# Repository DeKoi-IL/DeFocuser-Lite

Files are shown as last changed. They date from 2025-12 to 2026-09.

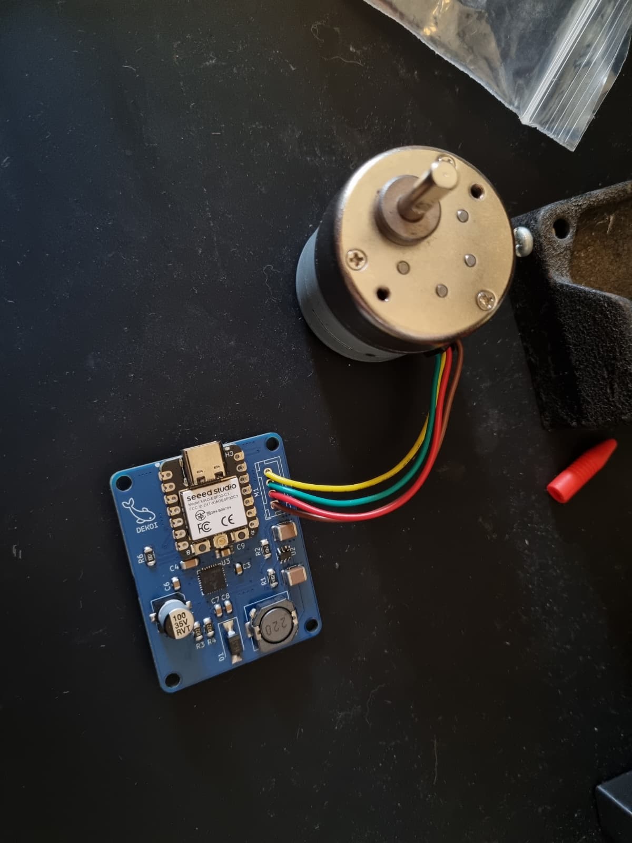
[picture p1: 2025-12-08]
Images/Assembly.jpg

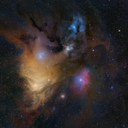
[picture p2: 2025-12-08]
Code/ASCOM_Driver/Resources/dekoi.bmp

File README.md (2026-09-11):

# DeFocuser-Lite
An open source DIY focus motor with automatic range calibration.

This focuser uses the same motor used by ZWO in the older EAF models (Non pro models)
The 3d models are also modelled based on ZWO's front plate so whatever focuser the eaf is compatible with, this is also compatible.
Powered by USB C 5V.
Includes a single button for manual focusing (each press changes direction).




## 3D Models

There are multiple versions for models.
You can get the motor ZWO used in their older models (described below, imaged above)
Or you could use a basic BYJ motor with a simple modification (How to modify: https://www.youtube.com/watch?v=kCoWSqSAGug)
Its great for lenses with suitable reduction!
WhatsApp Image 2026-03-04 at 00 19 02
WhatsApp Image 2026-01-04 at 11 39 28
WhatsApp Image 2026-03-04 at 00 26 04

Or you could retrofit the motor and front plate of the really old 12V ZWO focuser
WhatsApp Image 2026-01-10 at 22 27 24

All versions can be found in the 3d models folder

## App
Each app instance owns one focuser (one COM port) and funnels commands from multiple ASCOM clients to that focus motor. Run one instance per focuser — e.g. a main scope and a piggybacked guide/lens defocuser.

The hub owns all configuration, including which focuser ASCOM clients talk to: the driver has no setup dialog of its own, and pressing Setup in NINA/SGP just brings the hub forward. With a single focuser there is nothing to configure — the first hub to connect claims the ASCOM slot. Running several, click **Use this hub** in the Connection panel of the one you want ASCOM to drive.
The app has many extra controls not possible to implement in control software like nina, sgp etc...


## Disclaimer
This is NOT a beginner friendly project, since its all SMD components.
But this also is not a hard SMD project, just need the right tools.
Mainly a hot plat and\or hot air gun.
This is one of my first SMD projects, and im positive this has a LOT of room for improvement.
Please do feel free to reach out for contribution!

## BOM
For the motor you need to search for this motor: 35YF22GN120R-TF0
I bought it from this Ali Express seller (cheapest i found), but feel free to try and source it yourself:
https://he.aliexpress.com/item/1005004214871047.html

Technically, this should work with any 2 phase 4 wire stepper motor (as long as it doesn't draw too much current).
You'd just need to redesign the 3d model to fit your motor.

I've actually tested on a Nema17 39mm motor, and it seems to work fine, albeit low torque obviously.

The rest of the components are in the kicad folder BOM file.
*note: In the kicad project some components have LCSC part numbers, and some dont.
This is due to me using components i already had, and the rest i ordered from LCSC.
For the components without LCSC part number, you can just search by name in ali express for example.

## Hardware
The connection holes are meant to be fit with m3\4 heatset inserts (these: https://he.aliexpress.com/item/1005007481465353.html)
The PCB and backplate are held with m2 heatset inserts with m2 6mm screws.

## Software
The software is originally based on DarkSkyGeek's OAG focuser project.
A lot of the code has changed, most of it is different.
I'd like to  thank Julian for the inspiration 🙏

The current shipped app is a WPF rewrite (`Code/FocuserApp`) that replaces the older WinForms mediator (kept around as `Code/Focuser_App-Legacy/` for reference). It owns the serial connection to the focuser, exposes it to ASCOM clients via named pipes, and gives you a manual control UI on top.

This will allow multiple client connections to the focuser and give extra functionalities like:
- Auto\Manual limits calibration
- Manually settings position, max steps, reverse direction and more..
- Per-motor stall-detection sensitivity slider
- Speed selection (Fast / Normal / Slow)
- Live serial console (TX/RX, app events)

### Installing the app
The pre-built installer lives in the `Installer/` folder at the repo root:

```
Installer/DeKoi DeFocuser Lite Setup-<version>.exe
```

Run it. It installs both the ASCOM driver DLL (`ASCOM.DeKoi.DeFocuserLite.dll`) and the controller app (`ASCOM.DeKoi.DeFocuserApp.exe`), and registers the driver for COM under both 32-bit and 64-bit `regasm`. Requires ASCOM Platform 6.2 or later — the installer checks and bails out with a message if you don't have it.

If you want the prior WinForms version, the legacy installer source sits in `Code/Installer-Legacy/` and the legacy WinForms app in `Code/Focuser_App-Legacy/`. The standalone driver/installer that pre-dates all of this is preserved in `Code/Software-Legacy/`.

### Flashing the firmware
To flash the firmware on the ESP32, simply go to the arduino firmware folder, open the ino file in arduino IDE, compile and upload.
Make sure to have the ESP32 boards setup (Board manager) and set Xiao ESP32C3 (or S3)
And the following libraries:
- TMCStepper library by teemuatlut.
- EspSoftSerial by Dirk Kaar, Peter Lerup

## Building from source
The repo ships a one-shot build pipeline (`build.cmd` / `build.ps1`) that patches assembly versions, builds the ASCOM driver + the WPF controller, and compiles the Inno Setup installer in one go.

### Prerequisites
- Visual Studio 2019 / 2022 (Community / Pro / Enterprise / BuildTools — anything with MSBuild). The script auto-locates `MSBuild.exe`.
- [Inno Setup 6](https://jrsoftware.org/isdl.php) — script auto-locates `ISCC.exe`.
- ASCOM Platform 6.2 or later (the driver references `ASCOM.Utilities`).
- For the firmware: Arduino IDE with ESP32 boards + the libraries listed above.

### Build commands
From a regular `cmd.exe` prompt:

```cmd
build.cmd 2.1.0
build.cmd 2.1.0 -OutputDir D:\Releases
build.cmd 2.1.0 -SkipBuild
build.cmd 2.1.0 -Configuration Debug
```

From PowerShell:

```powershell
.\build.ps1 -Version 2.1.0
.\build.ps1 -Version 2.1.0 -OutputDir D:\Releases
.\build.ps1 -Version 2.1.0 -SkipBuild
.\build.ps1 -Version 2.1.0 -Configuration Debug
```

What it does:
1. Patches `AssemblyVersion` + `AssemblyFileVersion` in `Code/FocuserApp/Properties/AssemblyInfo.cs` and `Code/ASCOM_Driver/Properties/AssemblyInfo.cs`.
2. Builds the ASCOM driver (`Release | AnyCPU`).
3. Builds the WPF app (`Release | x64`).
4. Compiles `Code/FocuserApp/Installer/Setup.iss` with `ISCC`, injecting `/DMyAppVersion=<version>`.
5. Drops the resulting `DeKoi DeFocuser Lite Setup-<version>.exe` into `Installer/` (or whatever you pass to `-OutputDir`).

The fonts used by the app are **Inter** (UI) and **JetBrains Mono** (numeric readouts). Both are free OFL fonts; install them system-wide for pixel-perfect rendering — fallback to system fonts otherwise.

## Automatic limits calibration
This is very motor and configuration specific.
Not every motor behaves the same since the TMC's way of detecting stalls is back EMF measurement, and your motor might not behave as well as mine with the same configurations.

The first place to tune is the **Stall sense** slider in the controller app's Focuser Settings card — it scrubs the TMC's `SGTHRS` register from `128` (most sensitive) to `255` (least sensitive). The value persists to EEPROM, so you only set it once. Default is `211`.

If the slider alone doesn't get you where you want, there are a few firmware-side parameters you can tweak in `Code/Arduino_Firmware/Arduino_Firmware.ino`:

```
#define STALL_COUNT_THRESHOLD 2 // How many time should the stall interrupt be raised before we consider real stall
#define STALL_TIME_THRS 300     // In what time frame should these stalls be detected (in milliseconds)
#define STALL_GRACE_PERIOD 1000 // When starting motor, there are many false detections, how long should we ignore stall detections (in milliseconds)
```

Lets say the motor hits a hard physical limit but motor still makes noise trying to move (IE stall wasn't detected),
Try changing one of the following one by one (changing multiple parameters might make fine tuning harder):
- **Stall sense slider** = Start by sliding it toward the "Most sensitive" end, see if the stall is detected sooner.
- `STALL_TIME_THRS` = Increase this to allow slow stall detections to accumulate.
- `STALL_COUNT_THRESHOLD` = You could reduce this, but i suggest not doing that since that might increase false detections.

If this doesn't work, set `DEBUG` to `1` and watch the stall logs in the app's console — you'll see how often (or whether) stalls get detected. If they don't fire at all, or fire too slowly, slide stall sense further toward "Most sensitive".

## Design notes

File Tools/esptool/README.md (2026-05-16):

# esptool.exe (required for firmware updates)

The hub bundles `esptool.exe` so it can flash ESP32-C3 firmware updates over
the existing USB-serial connection — no Python install needed on user
machines.

## Drop the binary here

Place the Windows single-file build of esptool at:

```
Tools/esptool/esptool.exe
```

Download the latest standalone Windows release from:
<https://github.com/espressif/esptool/releases>

Pick the asset named like `esptool-vX.Y.Z-win64.zip`, extract, and copy
`esptool.exe` into this folder. Tested with v4.7+ (any version that supports
the `esp32c3` chip target works).

## What uses it

- **Build** — `build.ps1` does not require esptool itself, but the installer
  (`Code/FocuserApp/Installer/Setup.iss`) picks the binary up from this folder
  via `Source: "Tools\esptool\esptool.exe"`. The line is marked
  `skipifsourcedoesntexist`, so a missing binary will silently skip bundling
  rather than break the build, but the hub's firmware-update feature will be
  disabled on user installs.
- **Runtime** — `Services/FirmwareFlasher.cs` resolves the bundled binary at
  `{app}\tools\esptool.exe` and invokes it with:
  ```
  esptool.exe --chip esp32c3 --port COMx --baud 921600 \
      --before default_reset --after hard_reset \
      write_flash 0x0 firmware.bin
  ```

## Why not auto-download?

Keeping the binary out of git avoids a ~10MB blob in version history. CI or
release pipelines can fetch it via the URL above during the release build.

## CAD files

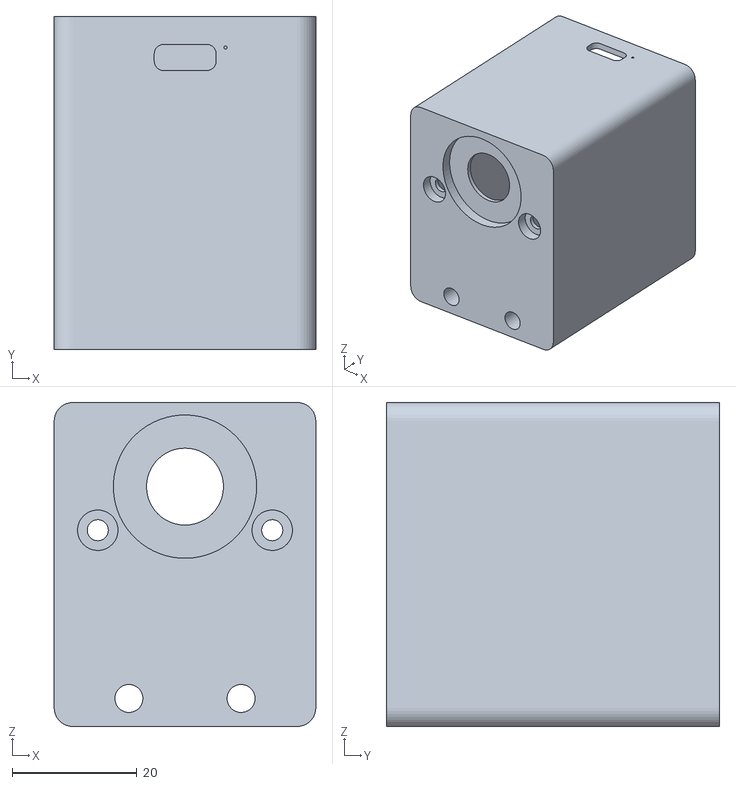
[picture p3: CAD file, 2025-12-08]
3D Models/Body.stl
42.0 x 53.5 x 52.0

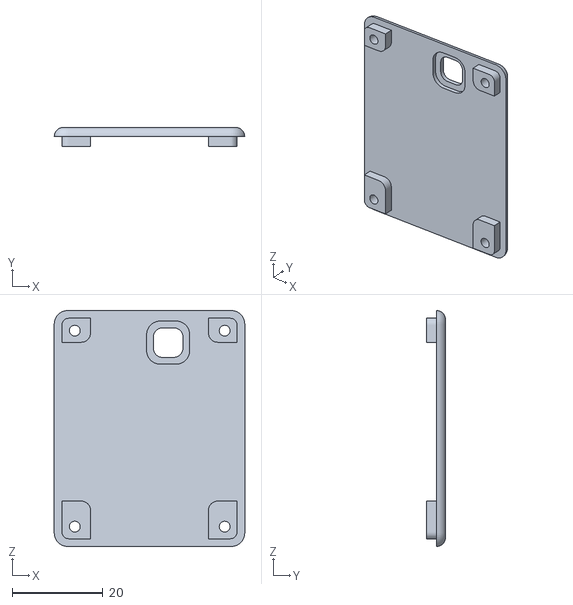
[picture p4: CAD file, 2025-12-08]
3D Models/BackPlate.stl
42.0 x 4.20 x 52.0

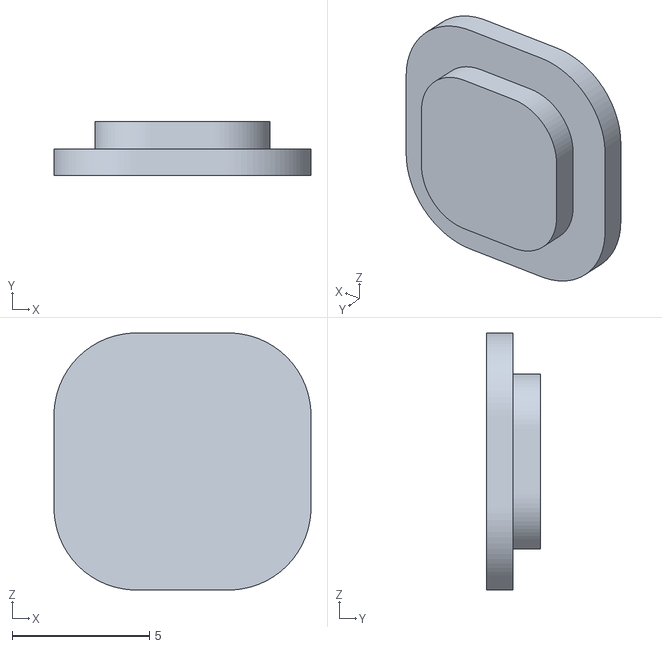
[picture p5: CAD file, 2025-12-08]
3D Models/Button.stl
9.35 x 1.95 x 9.35

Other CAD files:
3D Models/DeFocuser Lite.f3d

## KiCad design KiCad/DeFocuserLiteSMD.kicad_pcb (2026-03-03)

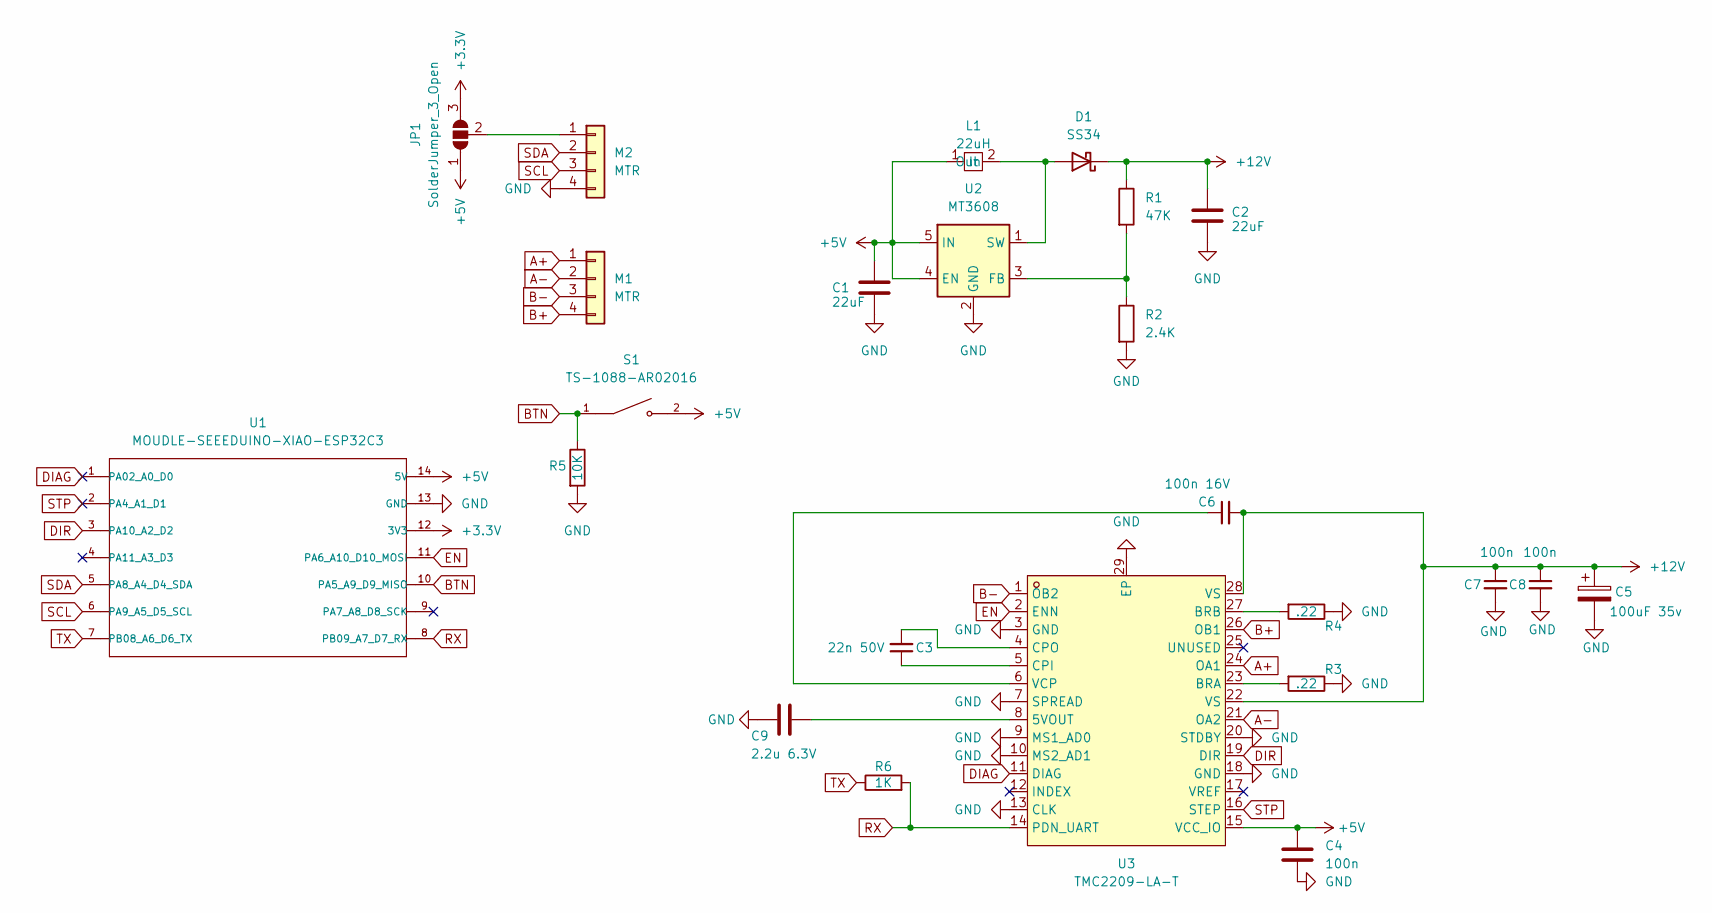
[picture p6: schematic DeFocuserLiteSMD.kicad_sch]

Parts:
C1, C2: 22uF; C_1812_4532Metric; LCSC Part C5348165
C3: 22n 50V; C_0805_2012Metric; LCSC Part C2175869
C4: 100n; C_1206_3216Metric; LCSC Part C2180991
C5: 100uF 35v; CP_Elec_6.3x7.7; LCSC Part C2836442
C6: 100n 16V; R_0805_2012Metric; LCSC Part C2170367
C7, C8: 100n; C_0805_2012Metric; LCSC Part C2170367
C9: 2.2u 6.3V; C_0805_2012Metric; LCSC Part C520034
D1: SS34; D_SMA-SMB_Universal_Handsoldering; LCSC Part C908680
JP1: SolderJumper_3_Open; SolderJumper-3_P1.3mm_Open_RoundedPad1.0x1.5mm_NumberLabels
L1: 22uH; Inductor_CDRH104R; LCSC Part C87002
M1, M2: MTR; JST_XH_B4B-XH-A_1x04_P2.50mm_Vertical
R1: 47K; R_1206_3216Metric_Pad1.30x1.75mm_HandSolder; LCSC Part C2933708
R2: 2.4K; R_1206_3216Metric_Pad1.30x1.75mm_HandSolder; LCSC Part C2907446
R3, R4: .22; R_1210_3225Metric; LCSC Part C137099
R5: 10K; R_1206_3216Metric; LCSC Part C17902
R6: 1K; R_1206_3216Metric; LCSC Part C2907440
S1: TS-1088-AR02016; SW_TS-1088-AR02016; PARTREV N/A; LCSC Part C720477
U1: MOUDLE-SEEEDUINO-XIAO-ESP32C3; XIAO-ESP32C3-SMD
U2: MT3608; SOT-23-6; LCSC Part C84817
U3: TMC2209-LA-T; QFN-28_L5.0-W5.0-P0.50-BL-EP; LCSC Part C2150710

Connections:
+3.3V: JP1.3 (B), U1.12 (3V3)
+5V: C1.1, C4.1, JP1.1 (A), L1.1 (In), S1.2, U1.14 (5V), U2.4 (EN), U2.5 (IN), U3.15 (VCC_IO)
+12V: C2.1, C5.1, C6.2, C7.1, C8.1, D1.1 (K), R1.1, U3.22 (VS), U3.28 (VS)
A+: M1.1, U3.24 (OA1); also elsewhere on the board
A-: M1.2, U3.21 (OA2); also elsewhere on the board
B+: M1.4, U3.26 (OB1); also elsewhere on the board
B-: M1.3, U3.1 (OB2); also elsewhere on the board
BTN: R5.1, S1.1, U1.10 (PA5_A9_D9_MISO)
DIAG: U1.1 (PA02_A0_D0), U3.11 (DIAG)
DIR: U1.3 (PA10_A2_D2), U3.19 (DIR)
EN: U1.11 (PA6_A10_D10_MOSI), U3.2 (ENN)
GND: C1.2, C2.2, C4.2, C5.2, C7.2, C8.2, C9.2, M2.4, R2.2, R3.1, R4.1, R5.2, U1.13 (GND), U2.2 (GND), U3.3 (GND), U3.7 (SPREAD), U3.9 (MS1_AD0), U3.10 (MS2_AD1), U3.13 (CLK), U3.18 (GND), U3.20 (STDBY), U3.29 (EP); also elsewhere on the board
unnamed: D1.2 (A), L1.2 (Out), U2.1 (SW)
unnamed 13: JP1.2 (C), M2.1; also elsewhere on the board
unnamed: R1.2, R2.1, U2.3 (FB)
unnamed: C9.1, U3.8 (5VOUT)
unnamed: R3.2, U3.23 (BRA)
unnamed: R4.2, U3.27 (BRB)
unnamed: C3.1, U3.5 (CPI)
unnamed: C3.2, U3.4 (CPO)
unnamed: C6.1, U3.6 (VCP)
RX: R6.2, U1.8 (PB09_A7_D7_RX), U3.14 (PDN_UART)
SCL: M2.3, U1.6 (PA9_A5_D5_SCL); also elsewhere on the board
SDA: M2.2, U1.5 (PA8_A4_D4_SDA); also elsewhere on the board
STP: U1.2 (PA4_A1_D1), U3.16 (STEP)
TX: R6.1, U1.7 (PB08_A6_D6_TX)

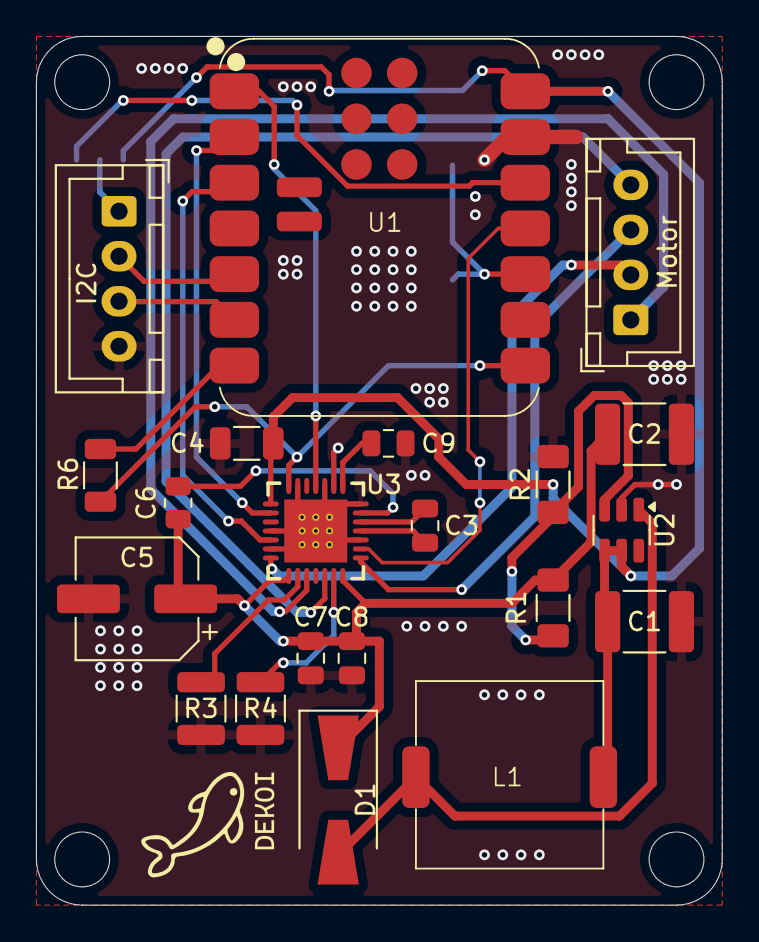
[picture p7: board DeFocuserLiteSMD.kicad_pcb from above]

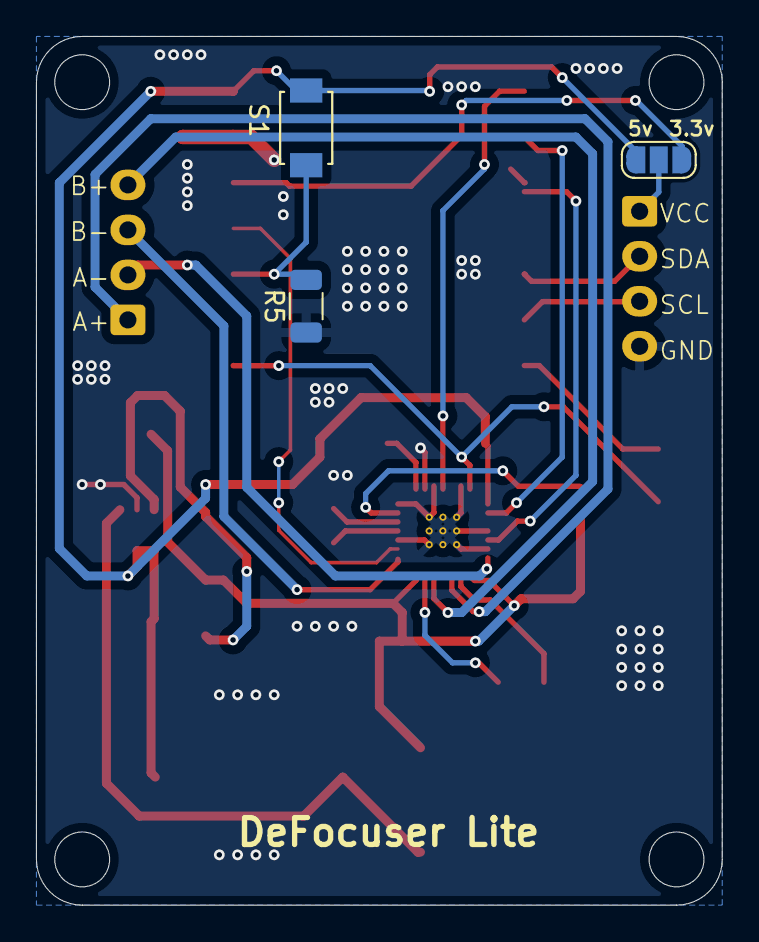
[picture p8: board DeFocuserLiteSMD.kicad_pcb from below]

Board: 2 copper layers, 38.1 x 48.3 mm, 24 parts (3 on the bottom side), 26 nets.

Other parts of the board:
I2C: MTR; JST_XH_B4B-XH-A_1x04_P2.50mm_Vertical
Motor: MTR; JST_XH_B4B-XH-A_1x04_P2.50mm_Vertical

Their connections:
A+: Motor.1; also elsewhere on the board
A-: Motor.2; also elsewhere on the board
B+: Motor.4; also elsewhere on the board
B-: Motor.3; also elsewhere on the board
GND: I2C.4; also elsewhere on the board
unnamed 13: I2C.1; also elsewhere on the board
SCL: I2C.3; also elsewhere on the board
SDA: I2C.2; also elsewhere on the board

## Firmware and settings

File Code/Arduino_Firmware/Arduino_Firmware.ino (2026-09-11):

#include <TMCStepper.h>
#include <SoftwareSerial.h>
#include <EEPROM.h>

#define DEBUG 0

// Board select. Bare tokens need distinct values, otherwise the #if/#elif
// comparisons below all collapse to 0 == 0 (undefined identifier -> 0) and
// the first branch always wins regardless of what MCU is set to.
#define ESP32C3     1  // current SMD board: I2C pins (D4/GPIO6, D5/GPIO7) freed to header M2
#define ESP32C3_OLD 2  // pre-rev board: STEP/DIR sat on the I2C pins
#define ESP32S3     3

// Default for a bare `arduino-cli compile`. build.ps1 passes -DMCU=... per
// variant, so a release build never rewrites this file. The pre-rev board is
// the default because every unit predating the SMD revision uses it.
#ifndef MCU
  #define MCU ESP32C3_OLD
#endif

// BOARD_ID is what the firmware reports over COMMAND:FOCUSER:GETBOARD and what
// the release .bin is named after. Keep the three in sync: a mismatch is how
// 2.3.0 shipped new-board pins to pre-rev hardware.
#if MCU == ESP32C3
  #define EN_PIN    10  // Enable          (D10 / GPIO10)
  #define DIR_PIN   4   // Direction       (D2  / GPIO4)
  #define STEP_PIN  3   // Step            (D1  / GPIO3)
  #define DIAG_PIN  2   // Stall detection (D0  / GPIO2)
  #define SW_RX 20
  #define SW_TX 21
  #define BUTTON_PIN 9
  #define BOARD_ID "esp32c3"
#elif MCU == ESP32C3_OLD
  #define EN_PIN    10  // Enable
  #define DIR_PIN   7   // Direction       (D5 / GPIO7 / SCL)
  #define STEP_PIN  6   // Step            (D4 / GPIO6 / SDA)
  #define DIAG_PIN  4   // Stall detection (D2 / GPIO4)
  #define SW_RX 20
  #define SW_TX 21
  #define BUTTON_PIN 9
  #define BOARD_ID "esp32c3-old"
#elif MCU == ESP32S3
  #define EN_PIN    9   // Enable          (D10 / GPIO9)
  #define DIR_PIN   3   // Direction       (D2  / GPIO3)
  #define STEP_PIN  2   // Step            (D1  / GPIO2)
  #define DIAG_PIN  1   // Stall detection (D0  / GPIO1)
  #define SW_RX 44
  #define SW_TX 43
  #define BUTTON_PIN 8
  #define BOARD_ID "esp32s3"
#endif

#define DRIVER_SERIAL_BAUD 57600

#define MAX_SPEED_DELAY 8000
#define MIN_SPEED_DELAY 14000

#define ACCELERATION_TIME 1000.0

#define DRIVER_ADDRESS 0b00  // TMC2209 address pin configuration
#define R_SENSE 0.22f        // Sense resistor value

//-- Constants ----------------------------------------------------------------

constexpr auto DEVICE_GUID = "dfafe960-d19c-4abd-af4a-4dc5f49775a3";

constexpr auto MSG_OK = "OK";
constexpr auto MSG_NOK = "NOK";

constexpr auto TRUE = "TRUE";
constexpr auto FALSE = "FALSE";

constexpr auto COMMAND_PING = "COMMAND:PING";
constexpr auto RESULT_PING = "RESULT:PING:OK:";

constexpr auto COMMAND_INFO = "COMMAND:INFO";
// build.ps1 patches the v__FIRMWARE_VERSION__ token in place before compile.
constexpr auto RESULT_INFO = "RESULT:INFO:DeKoi's DeFocuser Lite Firmware v2.4.1";

// Lets the hub confirm which pinout is actually running before it offers a
// firmware update, so a wrong pick in the MCU dropdown can be caught.
constexpr auto COMMAND_FOCUSER_GETBOARD = "COMMAND:FOCUSER:GETBOARD";
constexpr auto RESULT_FOCUSER_BOARD = "RESULT:FOCUSER:BOARD:";

constexpr auto COMMAND_FOCUSER_GETPOSITION = "COMMAND:FOCUSER:GETPOSITION";
constexpr auto RESULT_FOCUSER_POSITION = "RESULT:FOCUSER:POSITION:";

constexpr auto COMMAND_FOCUSER_GETMAXPOSITION = "COMMAND:FOCUSER:GETMAXPOSITION";
constexpr auto RESULT_FOCUSER_MAXPOSITION = "RESULT:FOCUSER:MAXPOSITION:";

constexpr auto COMMAND_FOCUSER_SETMAXPOSITION = "COMMAND:FOCUSER:SETMAXPOSITION:";
constexpr auto RESULT_FOCUSER_SETMAXPOSITION = "RESULT:FOCUSER:SETMAXPOSITION:";

constexpr auto COMMAND_FOCUSER_SETPOSITION = "COMMAND:FOCUSER:SETPOSITION:";
constexpr auto RESULT_FOCUSER_SETPOSITION = "RESULT:FOCUSER:SETPOSITION:";

constexpr auto COMMAND_FOCUSER_SETREVERSE = "COMMAND:FOCUSER:SETREVERSE:";
constexpr auto RESULT_FOCUSER_SETREVERSE = "RESULT:FOCUSER:SETREVERSE:";

constexpr auto COMMAND_FOCUSER_ISREVERSE = "COMMAND:FOCUSER:ISREVERSE";
constexpr auto RESULT_FOCUSER_ISREVERSE = "RESULT:FOCUSER:ISREVERSE:";

constexpr auto COMMAND_FOCUSER_ISMOVING = "COMMAND:FOCUSER:ISMOVING";
constexpr auto RESULT_FOCUSER_ISMOVING = "RESULT:FOCUSER:ISMOVING:";

constexpr auto COMMAND_FOCUSER_CALIBRATE = "COMMAND:FOCUSER:CALIBRATE";
constexpr auto RESULT_FOCUSER_CALIBRATE = "RESULT:FOCUSER:CALIBRATE:";

constexpr auto COMMAND_FOCUSER_ISCALIBRATING = "COMMAND:FOCUSER:ISCALIBRATING";
constexpr auto RESULT_FOCUSER_ISCALIBRATING = "RESULT:FOCUSER:ISCALIBRATING:";

constexpr auto COMMAND_FOCUSER_SETZEROPOSITION = "COMMAND:FOCUSER:SETZEROPOSITION";
constexpr auto RESULT_FOCUSER_SETZEROPOSITION = "RESULT:FOCUSER:SETZEROPOSITION:";

constexpr auto COMMAND_FOCUSER_MOVE = "COMMAND:FOCUSER:MOVE:";
constexpr auto RESULT_FOCUSER_MOVE = "RESULT:FOCUSER:MOVE:";

constexpr auto COMMAND_FOCUSER_HALT = "COMMAND:FOCUSER:HALT";
constexpr auto RESULT_FOCUSER_HALT = "RESULT:FOCUSER:HALT:";

constexpr auto COMMAND_FOCUSER_SETLIMIT = "COMMAND:FOCUSER:SETLIMIT";
constexpr auto RESULT_FOCUSER_SETLIMIT = "RESULT:FOCUSER:SETLIMIT:";

constexpr auto COMMAND_FOCUSER_SETSPEED = "COMMAND:FOCUSER:SETSPEED:";
constexpr auto RESULT_FOCUSER_SETSPEED = "RESULT:FOCUSER:SETSPEED:";

constexpr auto COMMAND_FOCUSER_GETSPEED = "COMMAND:FOCUSER:GETSPEED";
constexpr auto RESULT_FOCUSER_GETSPEED = "RESULT:FOCUSER:GETSPEED:";

constexpr auto SPEED_FAST = "FAST";
constexpr auto SPEED_NORMAL = "NORMAL";
constexpr auto SPEED_SLOW = "SLOW";

constexpr auto COMMAND_FOCUSER_SETSTALLTHRESHOLD = "COMMAND:FOCUSER:SETSTALLTHRESHOLD:";
constexpr auto RESULT_FOCUSER_SETSTALLTHRESHOLD = "RESULT:FOCUSER:SETSTALLTHRESHOLD:";

constexpr auto COMMAND_FOCUSER_GETSTALLTHRESHOLD = "COMMAND:FOCUSER:GETSTALLTHRESHOLD";
constexpr auto RESULT_FOCUSER_GETSTALLTHRESHOLD = "RESULT:FOCUSER:GETSTALLTHRESHOLD:";

constexpr auto COMMAND_FOCUSER_SETSTALLCOUNT = "COMMAND:FOCUSER:SETSTALLCOUNT:";
constexpr auto RESULT_FOCUSER_SETSTALLCOUNT = "RESULT:FOCUSER:SETSTALLCOUNT:";
constexpr auto COMMAND_FOCUSER_GETSTALLCOUNT = "COMMAND:FOCUSER:GETSTALLCOUNT";
constexpr auto RESULT_FOCUSER_GETSTALLCOUNT = "RESULT:FOCUSER:GETSTALLCOUNT:";

constexpr auto COMMAND_FOCUSER_SETSTALLWINDOW = "COMMAND:FOCUSER:SETSTALLWINDOW:";
constexpr auto RESULT_FOCUSER_SETSTALLWINDOW = "RESULT:FOCUSER:SETSTALLWINDOW:";
constexpr auto COMMAND_FOCUSER_GETSTALLWINDOW = "COMMAND:FOCUSER:GETSTALLWINDOW";
constexpr auto RESULT_FOCUSER_GETSTALLWINDOW = "RESULT:FOCUSER:GETSTALLWINDOW:";

constexpr auto COMMAND_FOCUSER_SETSTALLGRACE = "COMMAND:FOCUSER:SETSTALLGRACE:";
constexpr auto RESULT_FOCUSER_SETSTALLGRACE = "RESULT:FOCUSER:SETSTALLGRACE:";
constexpr auto COMMAND_FOCUSER_GETSTALLGRACE = "COMMAND:FOCUSER:GETSTALLGRACE";
constexpr auto RESULT_FOCUSER_GETSTALLGRACE = "RESULT:FOCUSER:GETSTALLGRACE:";

constexpr auto COMMAND_FOCUSER_SETSTALLENABLED = "COMMAND:FOCUSER:SETSTALLENABLED:";
constexpr auto RESULT_FOCUSER_SETSTALLENABLED = "RESULT:FOCUSER:SETSTALLENABLED:";
constexpr auto COMMAND_FOCUSER_GETSTALLENABLED = "COMMAND:FOCUSER:GETSTALLENABLED";
constexpr auto RESULT_FOCUSER_GETSTALLENABLED = "RESULT:FOCUSER:GETSTALLENABLED:";

// SGTHRS register is 8-bit. Higher value = less sensitive to stall detection.
// Slider exposes only the upper half (128-255) since values below half are
// far too sensitive for our motor and produce constant false positives.
constexpr uint8_t STALL_THRESHOLD_MIN = 128;
constexpr uint8_t STALL_THRESHOLD_MAX = 255;
constexpr uint8_t STALL_THRESHOLD_DEFAULT = 211;

constexpr uint8_t  STALL_COUNT_MIN = 1;
constexpr uint8_t  STALL_COUNT_MAX = 20;
constexpr uint8_t  STALL_COUNT_DEFAULT = 2;

constexpr uint16_t STALL_WINDOW_MIN = 50;
constexpr uint16_t STALL_WINDOW_MAX = 5000;
constexpr uint16_t STALL_WINDOW_DEFAULT = 300;

constexpr uint16_t STALL_GRACE_MIN = 0;
constexpr uint16_t STALL_GRACE_MAX = 10000;
constexpr uint16_t STALL_GRACE_DEFAULT = 1000;

constexpr bool STALL_ENABLED_DEFAULT = true;

constexpr auto ERROR_INVALID_COMMAND = "ERROR:INVALID_COMMAND";

// Bumped on every layout change. Old magic -> mismatch -> full re-init with
// defaults (no garbage read, no partial migration). Layout:
//   0..3   magic
//   4..7   position (uint32_t)
//   8..11  max_steps (uint32_t)
//   12     is_reverse (bool)
//   13     speed_setting (uint8_t)
//   14     stall_guard_threshold (uint8_t, SGTHRS)
//   15     stall_count_threshold (uint8_t)
//   16..17 stall_time_window (uint16_t, ms)
//   18..19 stall_grace_period (uint16_t, ms)
//   20     stall_enabled (bool)
const unsigned int EEPROM_MAGIC_NUMBER = 0x1234567B;
const unsigned int EEPROM_MAGIC_NUMBER_ADDR = 0;
const unsigned int EEPROM_POSITION_BASE_ADDR = 4;
const unsigned int EEPROM_MAX_STEPS_BASE_ADDR = 8;
const unsigned int EEPROM_REVERSE_BASE_ADDR = 12;
const unsigned int EEPROM_SPEED_BASE_ADDR = 13;
const unsigned int EEPROM_STALL_THRESHOLD_BASE_ADDR = 14;
const unsigned int EEPROM_STALL_COUNT_BASE_ADDR = 15;
const unsigned int EEPROM_STALL_WINDOW_BASE_ADDR = 16;
const unsigned int EEPROM_STALL_GRACE_BASE_ADDR = 18;
const unsigned int EEPROM_STALL_ENABLED_BASE_ADDR = 20;
const unsigned int EEPROM_SIZE = 21;

//-- VARIABLES ----------------------------------------------------------------

SoftwareSerial SoftSerial(SW_RX, SW_TX); // RX, TX
TMC2209Stepper driver(&SoftSerial, R_SENSE, DRIVER_ADDRESS);

// While moving, steps_left > 0
// When not moving, steps_left == 0
uint32_t steps_left;

enum Direction {
    forward = 1,
    backward = -1
} direction;

bool is_reverse = false;

// The current position, which we store in EEPROM
uint32_t position;
uint32_t max_steps = 100000;

// Speed setting: 0 = FAST, 1 = NORMAL (default), 2 = SLOW.
// speed_factor_x10 scales both the start and cruise step delays.
// Higher factor = longer delay per step = slower motor.
//   FAST   -> 10 (1.0x)
//   NORMAL -> 15 (1.5x, ~33% slower cruise)
//   SLOW   -> 20 (2.0x, ~50% slower cruise)
uint8_t speed_setting = 1;
uint8_t speed_factor_x10 = 15;

bool is_manually_jogging = false;
bool jog_direction = false;
int jogStartTime = 0;
const int jogGrace = 5;

bool is_calibrating = false;
bool forward_calibration_direction = true;
int calibration_step;
uint32_t outmost_position;

long acceleration_start_time = 0;

uint32_t ihold      = 2;   // low hold current
uint32_t irun       = 31; // full run current scale
uint32_t iholddelay = 4;   // small delay

uint8_t  stall_guard_threshold = STALL_THRESHOLD_DEFAULT;
uint8_t  stall_count_threshold = STALL_COUNT_DEFAULT;
uint16_t stall_time_window     = STALL_WINDOW_DEFAULT;
uint16_t stall_grace_period    = STALL_GRACE_DEFAULT;
bool     stall_enabled         = STALL_ENABLED_DEFAULT;

uint8_t stall_counter = 0;
int start_stall_time = 0;
int stall_delay = -1;
int stall_grace = -1;

// Function declaration
void stalled();
void stallInterrupt();
void calibrate();
bool HandleFreeCommand(String command);
bool HandleBlockingCommand(String command);
uint32_t lerpClamped(uint32_t a, uint32_t b, float t);

bool moveFocuser(long target_position);
void haltFocuser();
void setLimitFocuser();
void setMaxPosition(long value);

void applySpeedFactor();
void sendSpeed();
void setSpeed(String arg);
void sendStallThreshold();
void setStallThreshold(String arg);
void sendStallCount();
void setStallCount(String arg);
void sendStallWindow();
void setStallWindow(String arg);
void sendStallGrace();
void setStallGrace(String arg);
void sendStallEnabled();
void setStallEnabled(String arg);

void setup() 
{
  pinMode(EN_PIN, OUTPUT);
  pinMode(DIR_PIN, OUTPUT);
  pinMode(STEP_PIN, OUTPUT);
  pinMode(DIAG_PIN, INPUT);
  pinMode(BUTTON_PIN, INPUT);

  digitalWrite(EN_PIN, HIGH); // Disable

#if DEBUG
  delay(2000);
#endif

  Serial.begin(9600);

#if DEBUG
  Serial.println("Begin setup...");
#endif

  // Focuser setup
  steps_left = 0;
  direction = forward;
  position = 0;

  // Drive setup
  SoftSerial.begin(DRIVER_SERIAL_BAUD);
  driver.begin();
  driver.shaft(false);
  driver.toff(4); // Enables driver
  driver.blank_time(24);
  driver.rms_current(350); // Peak = RMS * 1.414, for USB max is 500ma divided by 1.414.
  driver.microsteps(8); // Set microsteps

  driver.en_spreadCycle(false); // Disable spreadCycle
  driver.pwm_autoscale(true); // Needed for StealthChop, harmless here
  driver.intpol(1);

  driver.irun(irun);
  driver.ihold(ihold);
  driver.iholddelay(iholddelay);
  driver.TCOOLTHRS(0xFFFFF);

  driver.semin(5);
  driver.semax(2);
  driver.sedn(0b01);

  // SGTHRS gets re-applied after EEPROM load below using the stored value.
  driver.SGTHRS(stall_guard_threshold);

  attachInterrupt(digitalPinToInterrupt(DIAG_PIN), stallInterrupt, RISING);

  delay(500); // Let driver initialize

  if (Serial)
  {
    Serial.flush();
  }

#if DEBUG
  Serial.print("Driver version: ");
  Serial.println(driver.version());
#endif

  unsigned int magic_number;
  EEPROM.begin(EEPROM_SIZE);
  EEPROM.get(EEPROM_MAGIC_NUMBER_ADDR, magic_number);
  if (magic_number == EEPROM_MAGIC_NUMBER) {
      // The value stored in EEPROM is trustworthy...
      EEPROM.get(EEPROM_POSITION_BASE_ADDR, position);
      EEPROM.get(EEPROM_MAX_STEPS_BASE_ADDR, max_steps);
      EEPROM.get(EEPROM_REVERSE_BASE_ADDR, is_reverse);
      EEPROM.get(EEPROM_SPEED_BASE_ADDR, speed_setting);
      EEPROM.get(EEPROM_STALL_THRESHOLD_BASE_ADDR, stall_guard_threshold);
      EEPROM.get(EEPROM_STALL_COUNT_BASE_ADDR, stall_count_threshold);
      EEPROM.get(EEPROM_STALL_WINDOW_BASE_ADDR, stall_time_window);
      EEPROM.get(EEPROM_STALL_GRACE_BASE_ADDR, stall_grace_period);
      EEPROM.get(EEPROM_STALL_ENABLED_BASE_ADDR, stall_enabled);

      // Speed byte may be garbage on EEPROM that pre-dates this field.
      // Coerce out-of-range values to NORMAL (default).
      if (speed_setting > 2) {
          speed_setting = 1;
          EEPROM.put(EEPROM_SPEED_BASE_ADDR, speed_setting);
          EEPROM.commit();
      }
      // Clamp stall threshold to allowed range.
      if (stall_guard_threshold < STALL_THRESHOLD_MIN) {
          stall_guard_threshold = STALL_THRESHOLD_DEFAULT;
          EEPROM.put(EEPROM_STALL_THRESHOLD_BASE_ADDR, stall_guard_threshold);
          EEPROM.commit();
      }
      if (stall_count_threshold < STALL_COUNT_MIN || stall_count_threshold > STALL_COUNT_MAX) {
          stall_count_threshold = STALL_COUNT_DEFAULT;
          EEPROM.put(EEPROM_STALL_COUNT_BASE_ADDR, stall_count_threshold);
          EEPROM.commit();
      }
      if (stall_time_window < STALL_WINDOW_MIN || stall_time_window > STALL_WINDOW_MAX) {
          stall_time_window = STALL_WINDOW_DEFAULT;
          EEPROM.put(EEPROM_STALL_WINDOW_BASE_ADDR, stall_time_window);
          EEPROM.commit();
      }
      if (stall_grace_period > STALL_GRACE_MAX) {
          stall_grace_period = STALL_GRACE_DEFAULT;
          EEPROM.put(EEPROM_STALL_GRACE_BASE_ADDR, stall_grace_period);
          EEPROM.commit();
      }
      applySpeedFactor();
  } else {
      // The position had never been stored in EEPROM. Initialize it to 0...
      position = 0;
      max_steps = 100000;
      is_reverse = false;
      speed_setting = 1;
      stall_guard_threshold = STALL_THRESHOLD_DEFAULT;
      stall_count_threshold = STALL_COUNT_DEFAULT;
      stall_time_window     = STALL_WINDOW_DEFAULT;
      stall_grace_period    = STALL_GRACE_DEFAULT;
      stall_enabled         = STALL_ENABLED_DEFAULT;
      applySpeedFactor();
      // Store it...
      EEPROM.put(EEPROM_POSITION_BASE_ADDR, position);
      EEPROM.put(EEPROM_MAX_STEPS_BASE_ADDR, max_steps);
      EEPROM.put(EEPROM_REVERSE_BASE_ADDR, is_reverse);
      EEPROM.put(EEPROM_SPEED_BASE_ADDR, speed_setting);
      EEPROM.put(EEPROM_STALL_THRESHOLD_BASE_ADDR, stall_guard_threshold);
      EEPROM.put(EEPROM_STALL_COUNT_BASE_ADDR, stall_count_threshold);
      EEPROM.put(EEPROM_STALL_WINDOW_BASE_ADDR, stall_time_window);
      EEPROM.put(EEPROM_STALL_GRACE_BASE_ADDR, stall_grace_period);
      EEPROM.put(EEPROM_STALL_ENABLED_BASE_ADDR, stall_enabled);
      // And mark the value as trustworthy...
      EEPROM.put(EEPROM_MAGIC_NUMBER_ADDR, EEPROM_MAGIC_NUMBER);

      EEPROM.commit();
  }

  // Apply persisted stall threshold (overrides setup() default).
  driver.SGTHRS(stall_guard_threshold);
}

void applySpeedFactor()
{
  switch (speed_setting) {
    case 1: speed_factor_x10 = 15; break; // NORMAL
    case 2: speed_factor_x10 = 20; break; // SLOW
    default: speed_factor_x10 = 10; break; // FAST
  }
}

void loop() 
{
  if(is_calibrating)
  {
    calibrationDelay();
  }
  else
  {
    int now = millis();

    int buttonsState = digitalRead(BUTTON_PIN);
    if (is_manually_jogging && buttonsState == LOW && now - jogStartTime > jogGrace)
    {
      is_manually_jogging = false;
      stop();
    }

    if(!is_manually_jogging && buttonsState == HIGH)
    {
      is_manually_jogging = true;

      if (position >= max_steps) jog_direction = false;
      else if (position <= 0)    jog_direction = true;
      else                       jog_direction = !jog_direction;

      jogStartTime = now;

      if (jog_direction) moveFocuser(max_steps);
      else               moveFocuser(0);
    }
  }

  if (Serial && Serial.available() > 0) 
  {
    String command = Serial.readStringUntil('\n');
    command.replace("\r","");
    
    bool handledFreeCommand = HandleFreeCommand(command);
    bool handledBlockingCommand = true;
    
    bool calibrationState = is_calibrating;
    if (!calibrationState)
    {
      handledBlockingCommand = HandleBlockingCommand(command);
    }

    if ((!handledFreeCommand && calibrationState) 
      || (!handledFreeCommand && !handledBlockingCommand && !calibrationState))
    {
      handleInvalidCommand();
    }
  }

  // Make the stepper motor move, if needed, 1 step at a time...
  step();
}

bool HandleFreeCommand(String command)
{
  if (command == COMMAND_PING) 
  {
    handlePing();
  }
  else if (command == COMMAND_FOCUSER_GETPOSITION) 
  {
    sendFocuserPosition();
  }
  else if (command == COMMAND_FOCUSER_GETMAXPOSITION)
  {
    sendMaxPosition();
  }
  else if (command == COMMAND_INFO)
  {
    sendFirmwareInfo();
  }
  else if (command == COMMAND_FOCUSER_GETBOARD)
  {
    sendBoard();
  }
  else if (command == COMMAND_FOCUSER_ISMOVING) 
  {
    sendFocuserState();
  }
  else if (command == COMMAND_FOCUSER_ISREVERSE) 
  {
    sendReverseState();
  }
  else if (command == COMMAND_FOCUSER_ISCALIBRATING)
  {
    sendIsCalibratingState();
  }
  else if (command == COMMAND_FOCUSER_GETSPEED)
  {
    sendSpeed();
  }
  else if (command == COMMAND_FOCUSER_GETSTALLTHRESHOLD)
  {
    sendStallThreshold();
  }
  else if (command == COMMAND_FOCUSER_GETSTALLCOUNT)
  {
    sendStallCount();
  }
  else if (command == COMMAND_FOCUSER_GETSTALLWINDOW)
  {
    sendStallWindow();
  }
  else if (command == COMMAND_FOCUSER_GETSTALLGRACE)
  {
    sendStallGrace();
  }
  else if (command == COMMAND_FOCUSER_GETSTALLENABLED)
  {
    sendStallEnabled();
  }
  else if (command == COMMAND_FOCUSER_HALT && is_calibrating)
  {
    haltFocuser();
  }
  else if (command == COMMAND_FOCUSER_SETLIMIT && is_calibrating)
  {
    setLimitFocuser();
  }
  else
  {
    return false;
  }

  return true;
}

bool HandleBlockingCommand(String command)
{
  if (command == COMMAND_FOCUSER_CALIBRATE) 
  {
    calibrate();
  }
  else if (command.startsWith(COMMAND_FOCUSER_SETREVERSE))
  {
    String arg = command.substring(strlen(COMMAND_FOCUSER_SETREVERSE));
    Serial.print(RESULT_FOCUSER_SETREVERSE);
    if (arg != TRUE && arg != FALSE)
    {
      Serial.println(MSG_NOK);
    }
    else
    {
      is_reverse = arg == TRUE;
      EEPROM.put(EEPROM_REVERSE_BASE_ADDR, is_reverse);
      Serial.println(MSG_OK);

      EEPROM.commit();
    }
  }
  else if (command.startsWith(COMMAND_FOCUSER_SETPOSITION)) 
  {
    String arg = command.substring(strlen(COMMAND_FOCUSER_SETPOSITION));
    int value = arg.toInt();
    setFocuserPosition(value);
  }
  else if (command.startsWith(COMMAND_FOCUSER_SETMAXPOSITION))
  {
    String arg = command.substring(strlen(COMMAND_FOCUSER_SETMAXPOSITION));
    setMaxPosition(arg.toInt());
  }
  else if (command == COMMAND_FOCUSER_SETZEROPOSITION) 
  {
    setFocuserZeroPosition();
  }
  else if (command.startsWith(COMMAND_FOCUSER_MOVE)) 
  {
    String arg = command.substring(strlen(COMMAND_FOCUSER_MOVE));
    int value = arg.toInt();

    Serial.print(RESULT_FOCUSER_MOVE);
    Serial.println(moveFocuser(value) ? MSG_OK : MSG_NOK);
  }
  else if (command == COMMAND_FOCUSER_HALT)
  {
    haltFocuser();
  }
  else if (command.startsWith(COMMAND_FOCUSER_SETSPEED))
  {
    String arg = command.substring(strlen(COMMAND_FOCUSER_SETSPEED));
    setSpeed(arg);
  }
  else if (command.startsWith(COMMAND_FOCUSER_SETSTALLTHRESHOLD))
  {
    String arg = command.substring(strlen(COMMAND_FOCUSER_SETSTALLTHRESHOLD));
    setStallThreshold(arg);
  }
  else if (command.startsWith(COMMAND_FOCUSER_SETSTALLCOUNT))
  {
    String arg = command.substring(strlen(COMMAND_FOCUSER_SETSTALLCOUNT));
    setStallCount(arg);
  }
  else if (command.startsWith(COMMAND_FOCUSER_SETSTALLWINDOW))
  {
    String arg = command.substring(strlen(COMMAND_FOCUSER_SETSTALLWINDOW));
    setStallWindow(arg);
  }
  else if (command.startsWith(COMMAND_FOCUSER_SETSTALLGRACE))
  {
    String arg = command.substring(strlen(COMMAND_FOCUSER_SETSTALLGRACE));
    setStallGrace(arg);
  }
  else if (command.startsWith(COMMAND_FOCUSER_SETSTALLENABLED))
  {
    String arg = command.substring(strlen(COMMAND_FOCUSER_SETSTALLENABLED));
    setStallEnabled(arg);
  }
  else
  {
    return false;
  }

  return true;
}

//-- UTILITY FUNCTIONS -----------------------------------------------------
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

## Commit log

2025-12-08 Part number update
    [DeFocuserLiteSMD.kicad_sch]
2025-12-09 Fixed resistor value + reexported BOM
    [DeFocuserLiteSMD.kicad_sch]
2025-12-09 Added lcsc part numbers with in stock components
    [DeFocuserLiteSMD.kicad_sch]
2026-03-03 Trying V2 with better pcb layout to expose I2C, and new driver with standalone app integrated as a mediator
    [DeFocuserLiteSMD.kicad_pcb, DeFocuserLiteSMD.kicad_sch]
2026-03-04 New gerbers and BOM
    [DeFocuserLiteSMD-B_Cu.gbr, DeFocuserLiteSMD-B_Mask.gbr, DeFocuserLiteSMD-B_Paste.gbr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]
2026-05-06 Driver pointed at legacy app
2026-05-06 Full run current
2026-05-21 Stall settings in settings popup
    [Arduino_Firmware.ino]
2026-07-05 Updated pinout for new board revision (has old version option)
2026-09-11 Manual max travel + position, jog step multiplier
    Firmware gains COMMAND:FOCUSER:SETMAXPOSITION, which stores the new
    travel limit in EEPROM and pulls the saved position back into range when
    the limit shrinks. Rejected while the motor is moving, like SETPOSITION.
    Max travel and Position in the Focuser Settings card are now editable and
    write straight to the device on lost focus. Polled values bypass the
    public setters so a refresh never echoes back as a manual set.
    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
2026-09-11 Default released firmware to the pre-rev board pinout
    2.3.0 was the first release to carry the new-board pin map from 15796c7,
    which flipped ESP32C3 to mean the SMD revision (DIR 4 / STEP 3 / DIAG 2)
    and moved the original pins to ESP32C3_OLD. Every focuser in the field
    predates that revision, so flashing 2.3.0 left the firmware running
    normally while STEP/DIR pulses went to pins nothing is wired to: the
    position counter advanced and the motor stayed silent, from both serial
    moves and the physical button.
    MCU now defaults to ESP32C3_OLD so the released .bin matches the
    hardware people actually have. New boards need the define flipped by
    hand until the hub can ask which revision is connected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
    [Arduino_Firmware.ino]
2026-09-11 Per-board firmware builds and an MCU selector in the hub
    build.ps1 now compiles one .bin per board revision, selecting the pinout
    with -DMCU=<variant> instead of rewriting the sketch. The sketch guards
    its default with #ifndef so a bare arduino-cli compile still works, and
    each image is checked for the matching BOARD_ID before it is published --
    a silent failure of the -D override would otherwise ship the 2.3.0 bug
    again. Variants are ordered so the pre-rev build is uploaded first, which
    is what hubs at or below 2.3.1 pick up.
    Firmware answers COMMAND:FOCUSER:GETBOARD with its compiled BOARD_ID. The
    hub reads it on connect, adopts it as the selection, and refuses to flash
    while the device r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
    [Arduino_Firmware.ino]
2026-09-11 Move connectivity into the hub; driver Setup opens it
    The ASCOM driver no longer configures anything. Setup used to open a
    WinForms COM-port picker, which meant NINA's Setup button surfaced a
    second, competing window; it now resolves the hub and raises it over the
    existing pipe (IPC:SHOW), or launches one if none is running. The dialog
    and its resx are gone.
    Port selection moves to the hub. A hub claims the ASCOM slot by writing
    its port into the driver's ASCOM Profile -- automatically for the first
    hub to connect, so a single-focuser setup needs no configuration, and via
    "Use this hub" in the Connection panel when several are running. The
    driver reads that value, falls back to the only hub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
2026-09-11 Warn before the installer closes running apps; shorter board names
    The hub runs the installer with /SILENT, and Inno closes file-holding
    processes itself in silent mode rather than showing the "applications
    must be closed" page it displays interactively. An ASCOM client with the
    driver DLL loaded -- N.I.N.A., SGP -- was therefore terminated mid-session
    with no warning.
    The hub now queries the Restart Manager for processes holding the
    installed exe/DLL, which is the same mechanism Inno uses, and names them
    in a confirmation prompt before launching the installer. Both update
    paths go through it. No prompt appears when nothing else holds the files.
    This is deliberately separate from the existi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
    [Arduino_Firmware.ino]
